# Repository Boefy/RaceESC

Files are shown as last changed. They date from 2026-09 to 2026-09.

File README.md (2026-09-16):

# RaceESC
Custom 4 layer 2S ESC (for ~1/10 scale RC cars) with I2C, TCS, ABS and more! RaceESC is a compact, lightweight, 40A capable esc  with an I2C connector for other projects (telemetry, etc). This esc will support two way communication with a host microcontroller over i2c, 
allowing telemetry to be shared with it. The ESC will run am32 firmware, with traction control and abs built in, however connecting to a host MCU with an IMU, or a standalone I2C IMU, the ESC can more accurately react to slips using a PID controller.

Features:
- Super compact design (~27x25x10mm)
- High power and efficiency (Low RDS fets, High gate drive voltage, etc)
- 5V/3A integrated BEC
- JST SH I2C connector
- Regular 3 pin wire connector
- Super optimal phase layout
- TCS, ABS, Telemetry
- More to come (software-side)

CAD:
- Simple 2 part enclosure held together with 4 M2x10mm screws
- looks super cool

CAD

Wiring Diagram:
Front:

Top side wiring diagram
Back:

Bottom side wiring diagram



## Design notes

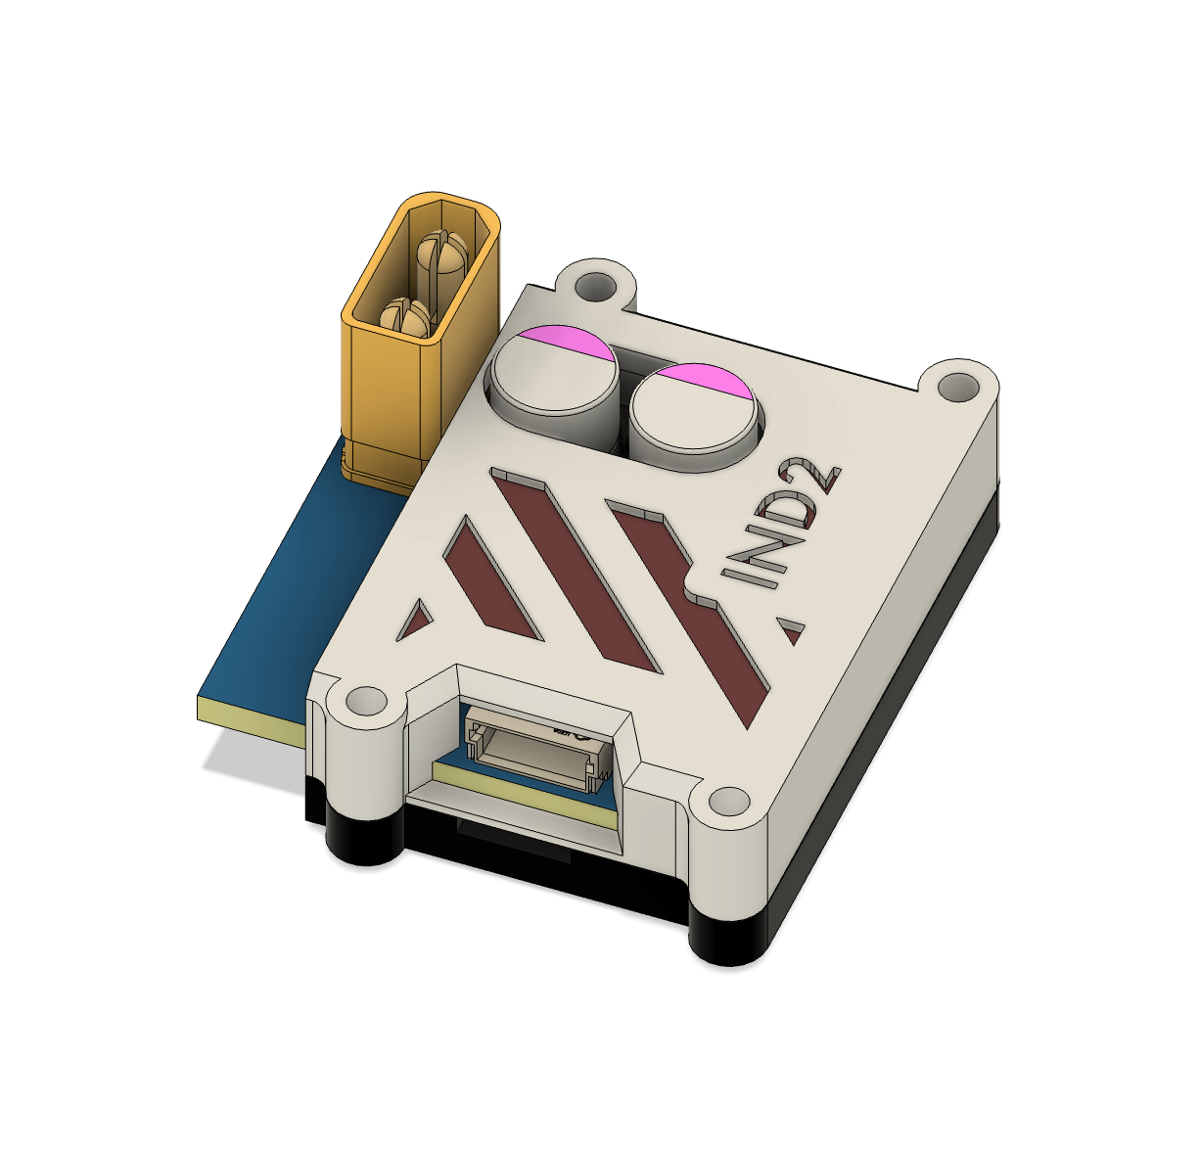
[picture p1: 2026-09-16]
RaceESC/Pictures/CAD.png

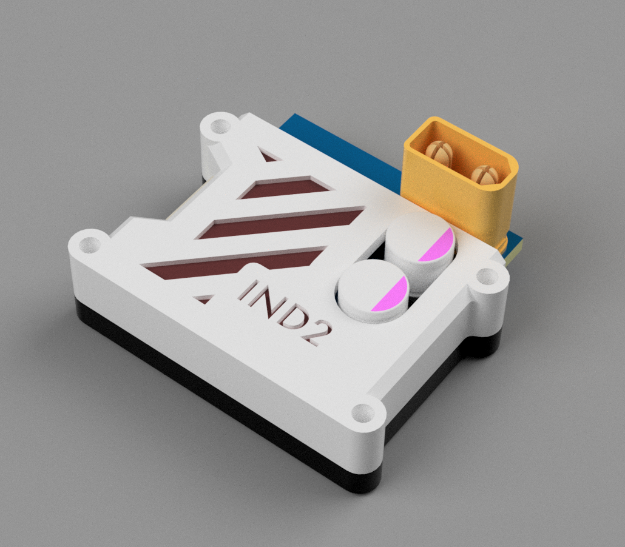
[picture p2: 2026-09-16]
RaceESC/Pictures/Render.png

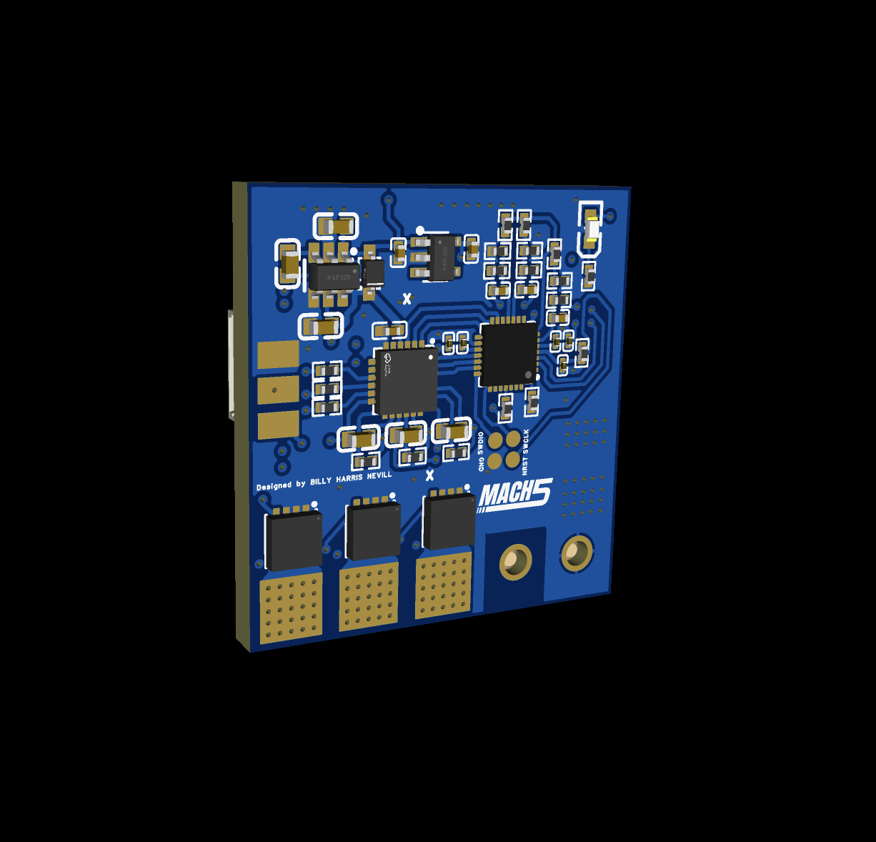
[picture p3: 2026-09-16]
RaceESC/Pictures/Back bit.png

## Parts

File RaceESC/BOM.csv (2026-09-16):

No. | Quantity | Comment | Designator | Footprint | Value | Manufacturer Part | Manufacturer | Supplier Part | Supplier
1 | 3 | 470nF | C1,C2,C5 | C0603 |  | C0603C474K9RAC7867 | KEMET(基美) | C3872363 | LCSC
2 | 1 | 100nF | C4 | C0402 |  | AC0402KRX7R9BB104 | YAGEO(国巨) | C2888326 | LCSC
3 | 3 | 22uF | C8,C11,C12 | C1210 | 22uF | CL32B226KAJNNNE | SAMSUNG(三星) | C309062 | LCSC
4 | 1 | 75pF | C13 | C0402 | 75pF | CC0402FRNPO9BN750 | YAGEO(国巨) | C541439 | LCSC
5 | 2 | 1uF | C21,C22 | C0402 | 1uF | C0402X5R105K160NT | SANYEAR(叁叶源) | C466611 | LCSC
6 | 2 | 220uF | C27,C28 | CAP-SMD_BD6.3-L6.6-W6.6-LS7.3-FD | 220uF | MA25V220M6X8 | JIERR(捷而瑞) | C46550464 | LCSC
7 | 3 | 100nF | C31,C33,C35 | C0402 | 100nF | CL05B104KB54PNC | SAMSUNG(三星) | C307331 | LCSC
8 | 3 | 4.7uF | C32,C34,C36 | C0805 | 4.7uF | GRM21BZ71H475KE15L | muRata(村田) | C437557 | LCSC
9 | 3 | 1nF | C37,C38,C39 | C0402 | 1nF | 0402B102K500NT | FH(风华) | C1523 | LCSC
10 | 1 | 100nF | C40 | C0402 | 100nF | CC0402X7R50V104KN | TORCH(火炬) | C53084447 | LCSC
11 | 1 | 100nF | C41 | C0402 | 100nF | ¨ | TORCH(火炬) | C53084447 | LCSC
12 | 3 | 3.3uF | C42,C43,C44 | C0603 | 3.3uF | CGA0603X5R335M250JT | HRE(芯声) | C51704734 | LCSC
13 | 4 | 100nF | C45,C46,C47,C50 | C0201 | 100nF | C0201D5R104K160NTA | EYANG(宇阳科技) | C778344 | LCSC
14 | 1 | 1uF | C49 | C0201 | 1uF | HGC0201R5105M160NTCJ | Chinocera(华瓷) | C33545999 | LCSC
15 | 1 | XT30UPB-M | CN1 | CONN-TH_XT30UPB-M |  | XT30UPB-M | AMASS(艾迈斯) | C428721 | LCSC
16 | 1 | 1N5817WS | D1 | SOD-323_L1.8-W1.3-LS2.5-RD |  | 1N5817WS | HXY MOSFET(华轩阳电子) | C41424805 | LCSC
17 | 4 | Test-Point | GND,NRST,SWCLK,SWDIO | Test-Point-0.5mm
18 | 1 | 5.6uH | L2 | IND-SMD_L7.0-W6.6_FXL0630 |  | FXL0630-5R6-M | cjiang(长江微电) | C475914 | LCSC
19 | 1 | ME6211C33M5G-N | LDO1 | SOT-23-5_L3.0-W1.7-P0.95-LS2.8-BL |  | ME6211C33M5G-N | MICRONE(南京微盟) | C82942 | LCSC
20 | 1 | SZYY0603G | LED1 | LED0603-R-RD_GREEN |  | SZYY0603G | yongyu(永裕光电) | C434420 | LCSC
21 | 1 | SZYY0603B | LED2 | LED0603-R-RD_BLUE |  | SZYY0603B | yongyu(永裕光电) | C434421 | LCSC
22 | 1 | SM05B-SRSS-G-TB(LF)(SN) | P1 | CONN-SMD_SM05B-SRSS-G-TB-LF-SN |  | SM05B-SRSS-G-TB(LF)(SN) | JST | C265419 | LCSC
23 | 6 | BSZ034N04LS | Q25,Q26,Q27,Q28,Q29,Q30 | PG-TSDSON-8_L3.3-W3.3-P0.65-BL-1 |  | BSZ034N04LS | Infineon(英飞凌) | C534652 | LCSC
24 | 1 | 49.9Ω | R22 | R0402 | 49.9Ω | RC0402FR-0749R9L | YAGEO(国巨) | C87044 | LCSC
25 | 9 | 100kΩ | R23,R55,R56,R57,R58,R59,R60,R61,R62 | R0402 | 100kΩ | 0402WGF1003TCE | UNI-ROYAL(厚声) | C25741 | LCSC
26 | 1 | 13.3kΩ | R24 | R0402 | 13.3kΩ | 0402WGF1332TCE | UNI-ROYAL(厚声) | C122547 | LCSC
27 | 3 | 220Ω | R30,R32,R48 | R0402 | 220Ω | 0402WGF2200TCE | UNI-ROYAL(厚声) | C25091 | LCSC
28 | 3 | 1.6kΩ | R45,R46,R47 | R0402 | 1.6kΩ | 0402WGF1601TCE | UNI-ROYAL(厚声) | C4908 | LCSC
29 | 6 | 15Ω | R49,R50,R51,R52,R53,R54 | R0402 | 15Ω | CQ02WGJ0150TCE | UNI-ROYAL(厚声) | C2770753 | LCSC
30 | 1 | NSG2065Q | U4 | QFN-24_L4.0-W4.0-P0.50-TL-EP2.8 |  | NSG2065Q | WXNSIC(国硅集成) | C41414478 | LCSC
31 | 1 | AT32F421G8U7 | U5 | QFN-28_L4.0-W4.0-P0.40-TL-EP2.4 |  | AT32F421G8U7 | ARTERY(雅特力) | C2765098 | LCSC
32 | 1 | TPS54302DDCT | U17 | TSOT-23-6_L2.9-W1.6-P0.95-LS2.8-BR |  | TPS54302DDCT | TI(德州仪器) | C129370 | LCSC
33 | 1 | LM2665M6X/NOPB | U18 | SOT-23-6_L2.9-W1.6-P0.95-LS2.8-BR |  | LM2665M6X/NOPB | TI(德州仪器) | C201725 | LCSC
NON ESC components
No. | Description | Qty
1 | ST-Link v2 | 1
2 | PLA plastic | N/A
3 | 14-18AWG motor wire | 1
4 | 3 wire dupont cable | 1
5 | Soldering iron | 1
6 | M2x10 button head | 4

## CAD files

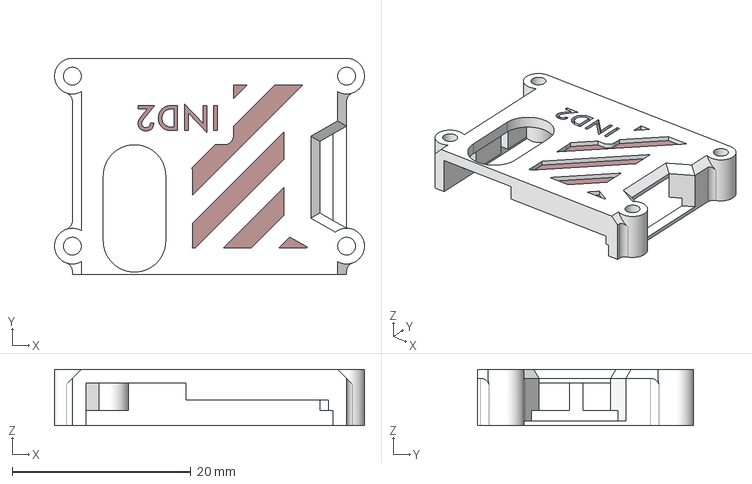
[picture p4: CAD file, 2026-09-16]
RaceESC/CAD/Top half.step
34.7 x 24.2 x 6.27 mm

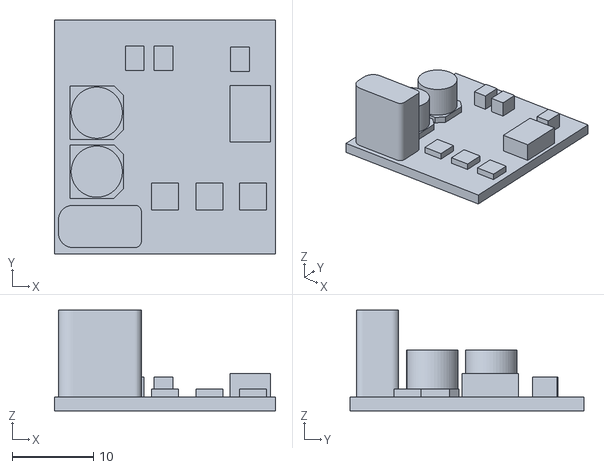
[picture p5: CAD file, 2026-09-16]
RaceESC/CAD/Simplified Pcb.stl
27.2 x 28.8 x 12.4

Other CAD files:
RaceESC/CAD/Top half.stl

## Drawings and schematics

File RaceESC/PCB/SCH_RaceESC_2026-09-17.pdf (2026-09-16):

## GND

## GND

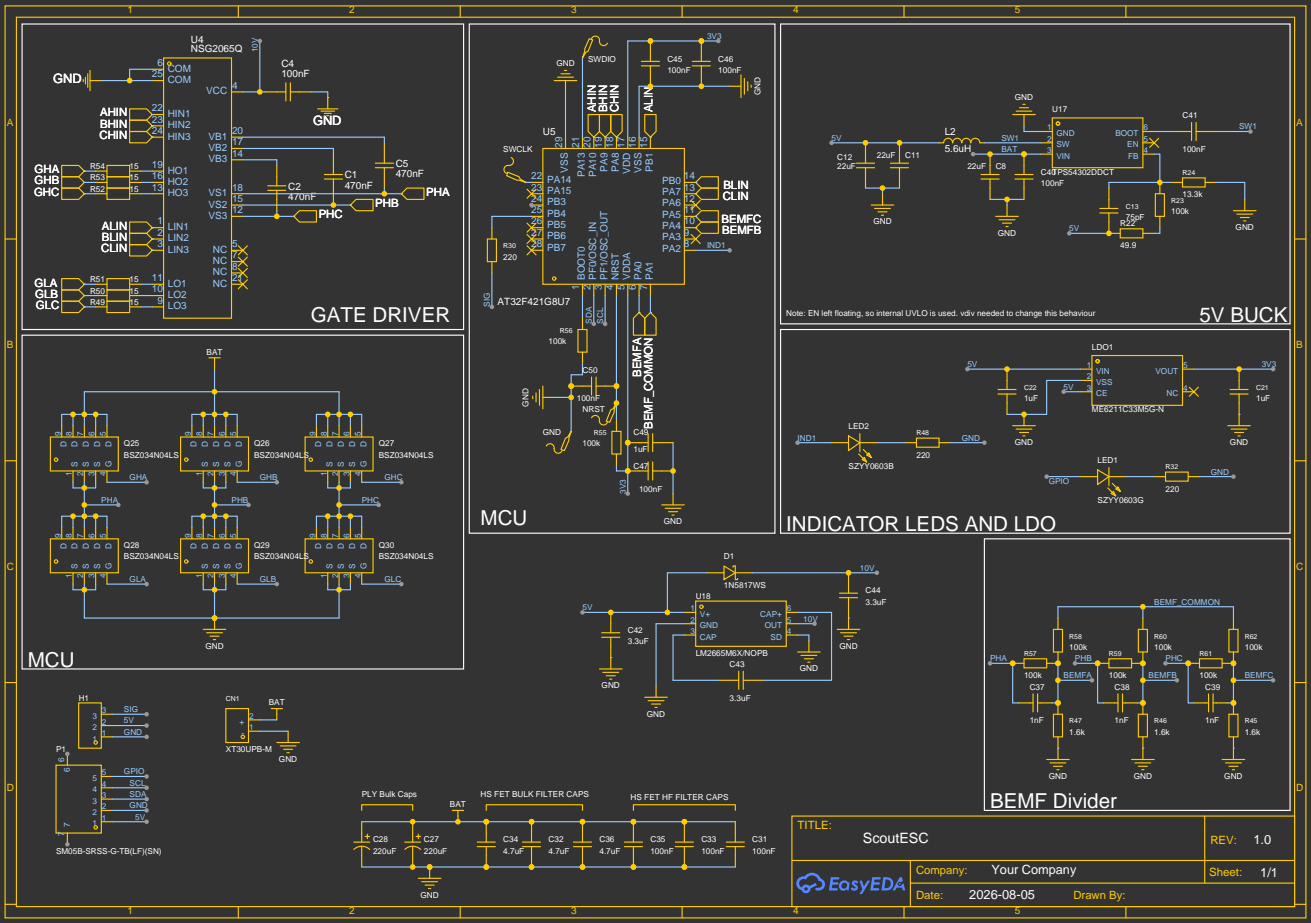
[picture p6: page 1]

Note: EN left floating, so internal UVLO is used. vdiv needed to change this behaviour

SZYY0603B
INDICATOR LEDS AND LDO

HS FET BULK FILTER CAPS
BAT

HS FET HF FILTER CAPS

SM05B-SRSS-G-TB(LF)(SN)

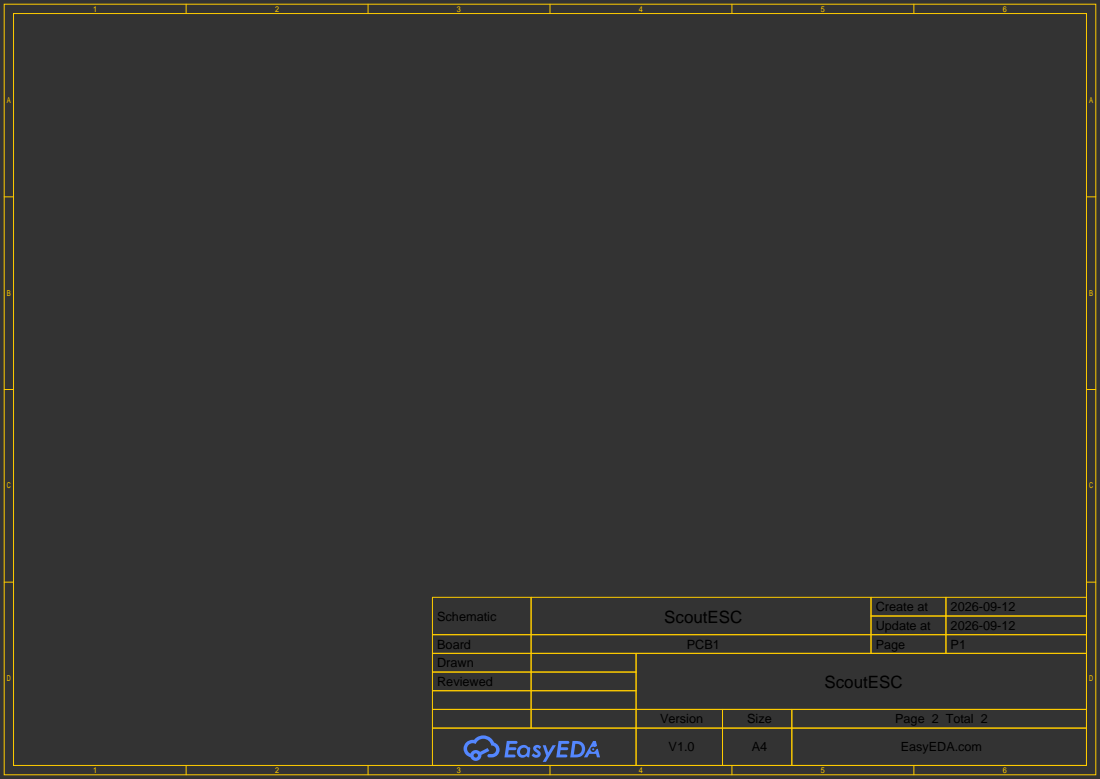
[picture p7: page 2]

Schematic | ScoutESC | Create at | 2026-09-12

Update at | 2026-09-12

Board | PCB1 | Page | P1
Drawn | | ScoutESC
Reviewed

Version | Size | Page 2 Total 2
V1.0 | A4 | EasyEDA.com

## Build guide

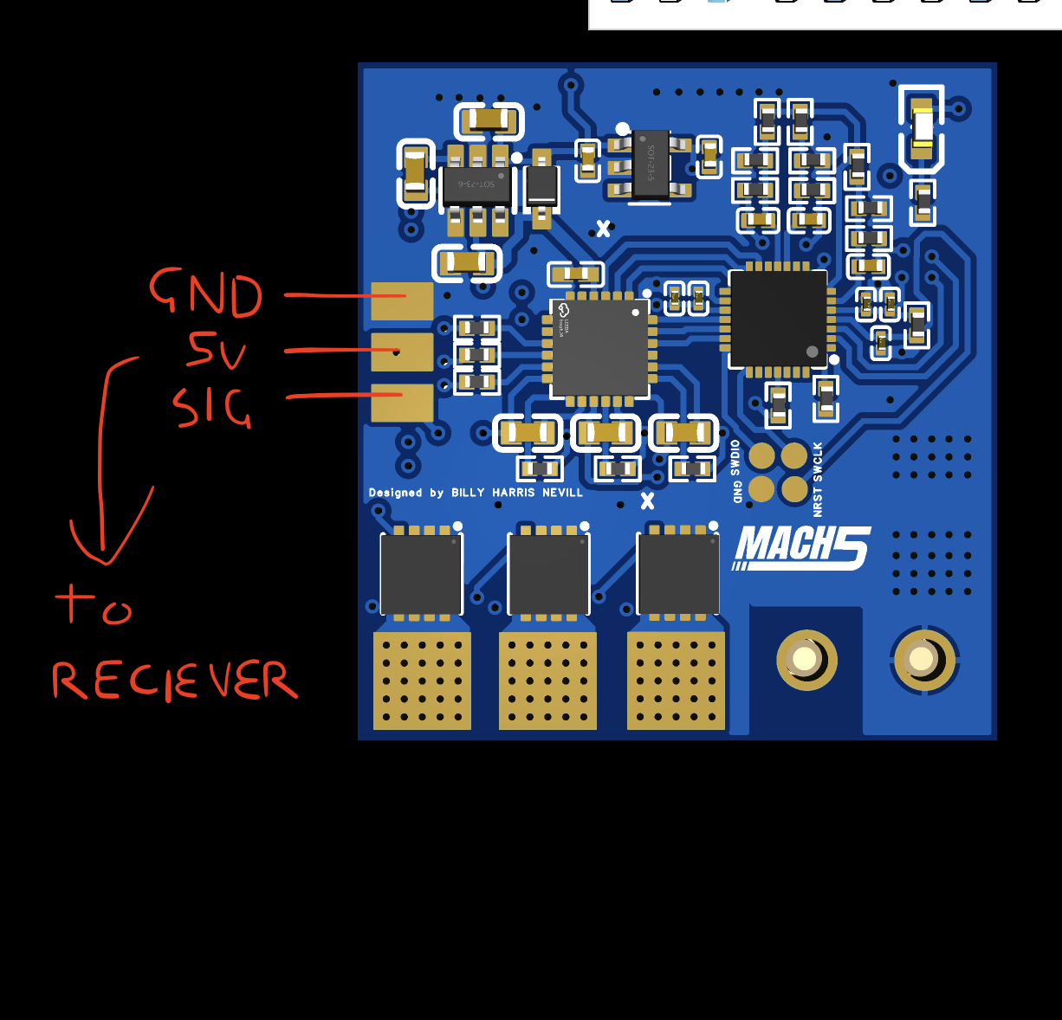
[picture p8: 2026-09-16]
RaceESC/PCB/Bottom side wiring diagram.png

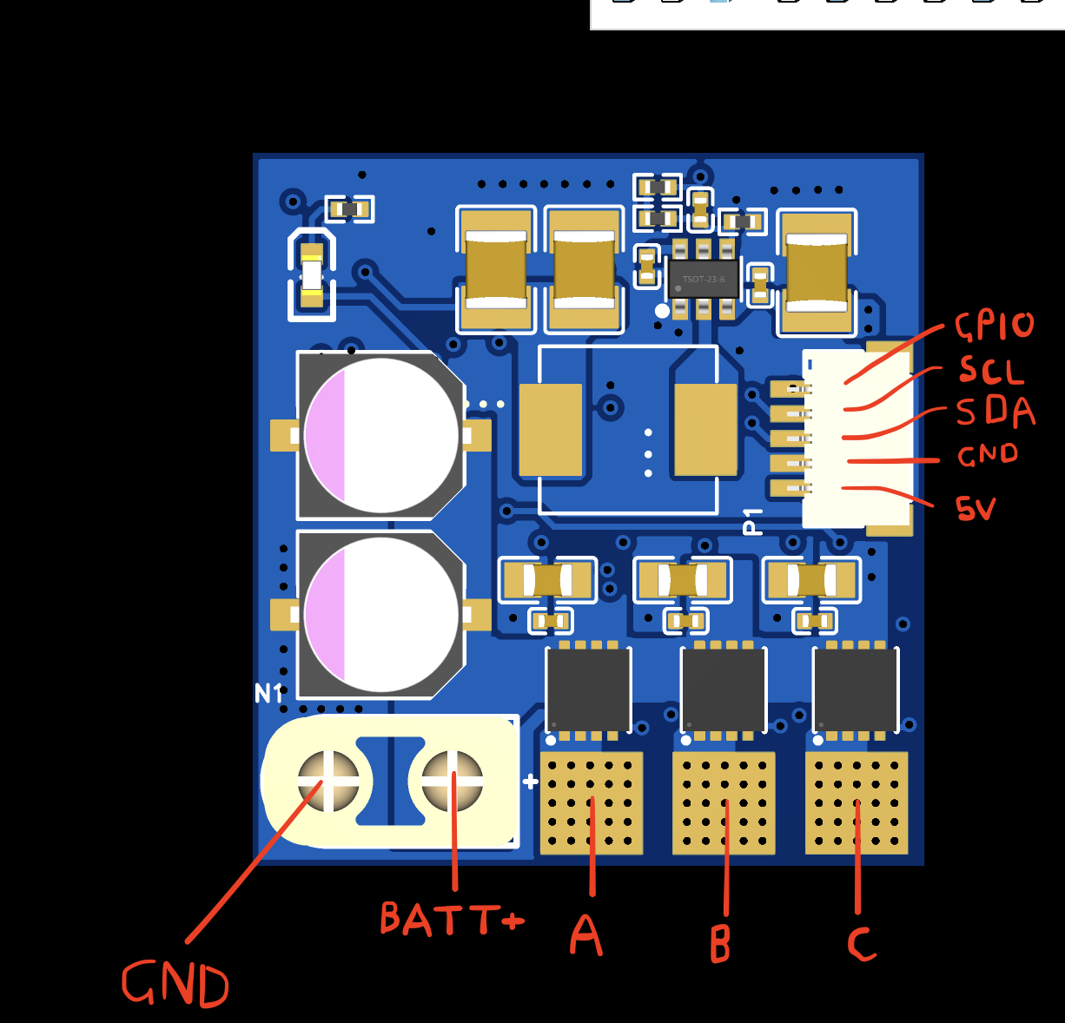
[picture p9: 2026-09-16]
RaceESC/PCB/Top side wiring diagram.png
